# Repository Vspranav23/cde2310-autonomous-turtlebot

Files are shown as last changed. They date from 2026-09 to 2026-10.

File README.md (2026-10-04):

# Autonomous Search, Rescue & Target-Firing Mobile Robot






An end-to-end autonomous mobile robotics system built on TurtleBot, featuring autonomous SLAM frontier exploration, real-time infrared thermal target acquisition, and a custom 3D-printed cam-cantilever-spring ping-pong ball launcher.

<p align="center">
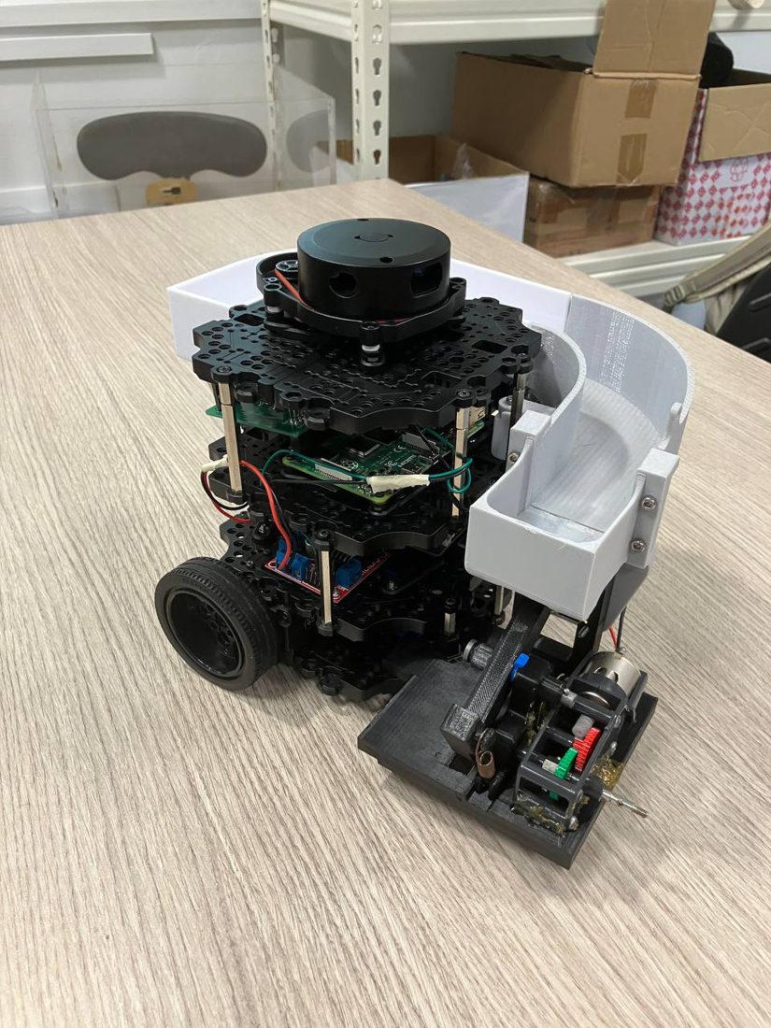
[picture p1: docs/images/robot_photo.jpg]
Assembled TurtleBot with hopper, launcher and thermal sensor
  
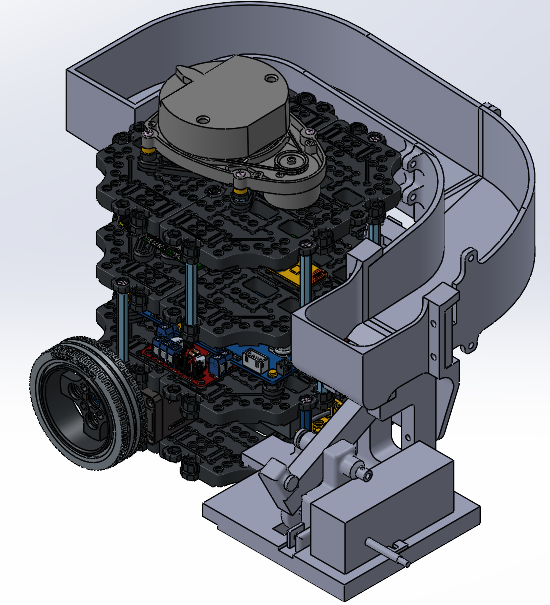
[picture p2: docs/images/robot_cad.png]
CAD model of the robot and payload
  
</p>

---

## System Architecture

```mermaid
graph LR
    subgraph Sensing_and_Perception["Sensing & Perception"]
        LiDAR["2D LiDAR Scanner"] --> SLAM["ROS 2 Cartographer / Nav2"]
        Thermal["AMG8833 8x8 IR Grid"] --> PyThermal["Thermal Vision Node"]
    end

    subgraph Decision_Making["Decision & Navigation"]
        SLAM --> Explorer["Frontier Exploration Node"]
        Explorer --> GoalGen["Nav2 Goal Controller"]
        PyThermal --> LockTarget["Target Lock & Alignment"]
    end

    subgraph Actuation["Actuation & Firing"]
        GoalGen --> Motors["TurtleBot Wheels"]
        LockTarget --> Driver["L298N Motor Driver (GPIO PWM)"]
        Driver --> Launcher["Cam-Cantilever-Spring Launcher"]
    end
```

## Key Features

- **Autonomous Frontier Exploration**: Nav2-integrated frontier exploration node driving complete environment mapping without teleoperation. Uses vectorized NumPy neighbor slicing for millisecond-level frontier discovery.
- **Thermal Heat-Source Tracking**: Real-time 8x8 thermal array processing identifying temperature differentials to detect victims or simulated heat targets.
- **Cam-Cantilever-Spring Launcher**: A geared DC motor rotates a custom surface cam that lifts a lever against an extension spring (14 mm stroke). When the lever drops off the cam step, the spring flicks it up to strike the ping-pong ball. Fed from a gravity hopper (8 balls + 1 in the launcher), and fired in 2 s / 4 s intervals.
- **Distributed ROS 2 Topology**: Workstation host handles heavy SLAM mapping and RViz visualization, while an onboard Raspberry Pi manages motor drivers, thermal I2C bus, and GPIO firing triggers.
- **Dual-Mode Simulation & Hardware Abstraction**: Seamlessly operates in real hardware mode (Raspberry Pi GPIO + Adafruit AMG8833) and standalone simulation mode (Gazebo / software testbed).

## Hardware Bill of Materials (BOM)

| Component | Model / Spec | Interface |
|---|---|---|
| Mobile Base | TurtleBot3 Burger / Custom Chassis | Dynamixel / UART |
| Onboard SBC | Raspberry Pi 4 Model B (4GB) | GPIO / I2C |
| Thermal Sensor | Panasonic / Adafruit AMG8833 | I2C (0x69) |
| Launcher Actuator | RE-260 DC motor + Ta72004 gearbox | L298N motor driver, GPIO PWM |
| 3D Printed Parts | Cam, lever, launcher body (PETG), hopper & sensor mount | Custom SolidWorks files in `/cad` |

## Subsystem Documentation

| Subsystem | README | Covers |
|---|---|---|
| Mechanical | [cad/README.md](cad/README.md) | Cam-cantilever-spring launcher, hopper, sensor mount, assembly, CAD file map |
| Electrical | [Electrical/README.md](Electrical/README.md) | PCB hat, wiring and pin map, power budget, BOM, Gerbers |
| Software | [Software/README.md](Software/README.md) | ROS 2 nodes, topics, thermal codes, launch files, tests |

## Repository Structure

```
├── cad/                     # 3D printable STL and STEP mechanical files
├── docs/                    # Figures (simulated map render)
├── Electrical/              # Schematics and sensor application datasheets
├── Software/
│   ├── cde2310/             # Main ROS 2 package (nodes, launch, params)
│   │   ├── launch/          # full_autonomy_launch.py, rpi.py, laptop.py
│   │   ├── config/          # nav2_params.yaml
│   │   └── cde2310/         # Thermal detection and motion control nodes
│   ├── workspace/           # Colcon workspace sources
│   ├── abandoned/           # Dropped prototypes (solenoid launcher)
│   └── tests/               # Automated maze simulation & unit test trials
└── LICENSE                  # MIT License
```

## Quick Start

### 1. Build the ROS 2 Workspace
```bash
cd Software/workspace
colcon build --symlink-install
source install/setup.bash
```

### 2. Launch Autonomous Search & Fire Routine
On the Raspberry Pi:
```bash
ros2 launch cde2310 rpi.py
```
On the workstation:
```bash
ros2 launch cde2310 laptop.py
```

### 3. Run Automated Maze Simulation Trials
To run the autonomous corridor exploration and thermal target neutralization testbed without physical hardware:
```bash
python Software/tests/test_maze_exploration.py
```
```

---

## Verification & Test Results

The autonomous navigation and target engagement logic was validated against a 12m × 12m maze environment with multi-corridor layouts and hidden heat targets:

```
======================================================================
  AUTOMATED SIMULATION TRIALS: CDE2310 AUTONOMOUS ROBOT
======================================================================
  STATUS: ALL TESTS PASSED (100% SUCCESS)
  - Vectorized Frontier Search: PASSED (0.002s avg)
  - Metric Coordinate Conversion: PASSED
  - Obstacle Blacklist Recovery: PASSED
  - Thermal Alignment & Launcher Firing: PASSED (2/2 targets neutralized)
  - Final Mapping Coverage: 88.0%
======================================================================
```

![Simulated maze (left) and the occupancy grid built during exploration (right)](docs/sim_map.png)

*Left: ground-truth maze with heat targets (stars) and start pose. Right: map uncovered by the simulated LiDAR (grey = unknown) and the poses where scans were taken. The sim moves the robot directly between frontiers without collision checking, so the line is not a drivable path. Regenerate with `python Software/tests/render_sim_map.py`.*

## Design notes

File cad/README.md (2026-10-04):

# Mechanical

The mechanical payload sits on a TurtleBot3 Burger. It has three parts:

- **Hopper:** a gravity-fed, single-stack hopper that holds the ping-pong balls.
- **Launcher:** a cam-cantilever-spring mechanism that flicks one ball at a time upward.
- **Sensor mount:** a holder at the front of the robot for the AMG8833 thermal camera.

All custom parts were modelled in SolidWorks and 3D printed. The launcher parts are PETG.

| Built robot | CAD |
|---|---|
|  |  |

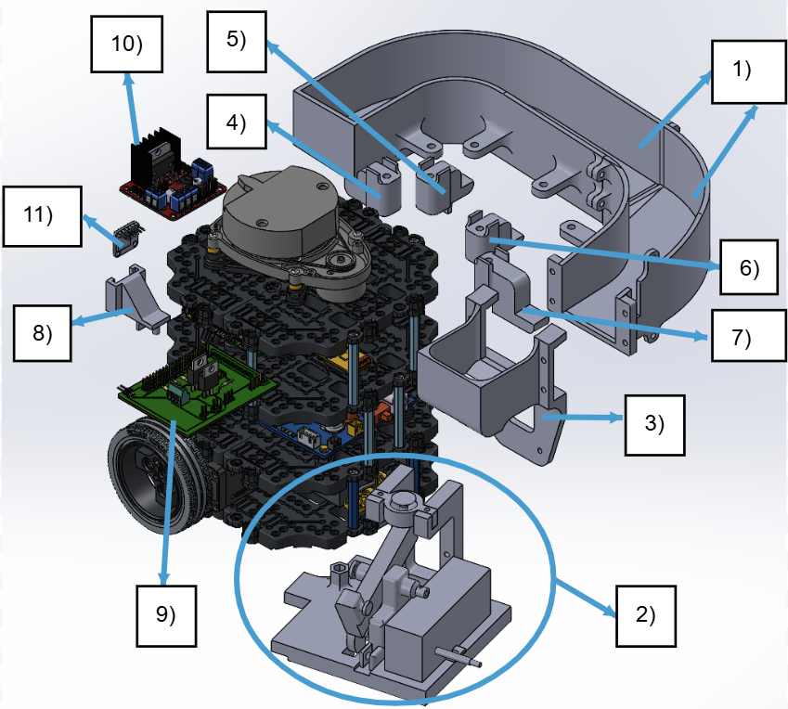
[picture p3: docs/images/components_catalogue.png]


*Components: 1 hopper, 2 launcher, 3 launcher mount, 4–7 spacers 1–4, 8 sensor mount, 9 PCB controller, 10 L298N motor driver, 11 AMG8833 thermal sensor.*

## Specifications

| Item | Value |
|---|---|
| Size (L × W × H) | 300 × 221 × 206 mm |
| Weight | 1575 g unladen, 1600 g with 9 balls |
| Ball capacity | 9 (8 in the hopper, 1 in the launcher) |
| Estimated launch height | 1.0–1.5 m |
| Launcher stroke | 14 mm spring extension, 2 mm pre-load |
| Launcher drive | RE-260 DC motor (3.0–4.5 V) + Ta72004 worm gearbox at 336:1 |

## Launcher: cam-cantilever-spring

A lever pivots on a pin in the launcher mount. One end of the lever rests on a custom surface cam and the other end is attached to an extension spring.

1. The geared motor turns the cam.
2. As the cam turns from its lowest to its highest point, it lifts the lever and stretches the spring.
3. When the lever reaches the cam's step, it drops off.
4. The spring snaps the lever back, and the lever strikes the ball upward.

| CAD | Printed launcher (PETG) |
|---|---|
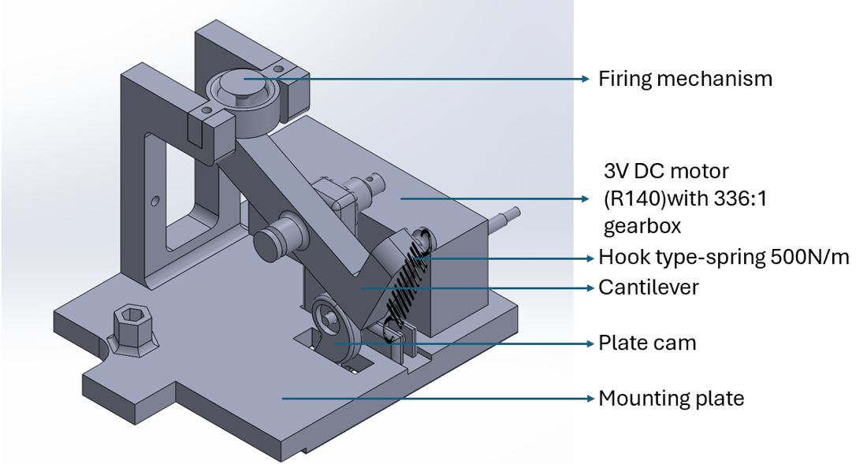
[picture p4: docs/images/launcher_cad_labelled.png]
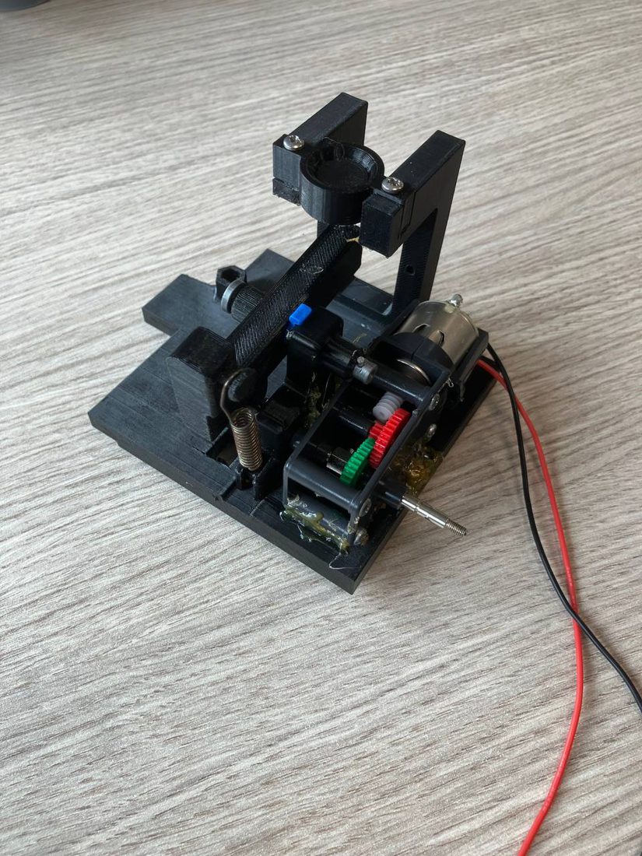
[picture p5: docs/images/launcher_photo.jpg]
|  |  |

| Spring loaded (lever on the cam) | Fired (lever flicked up into the firing pin) |
|---|---|
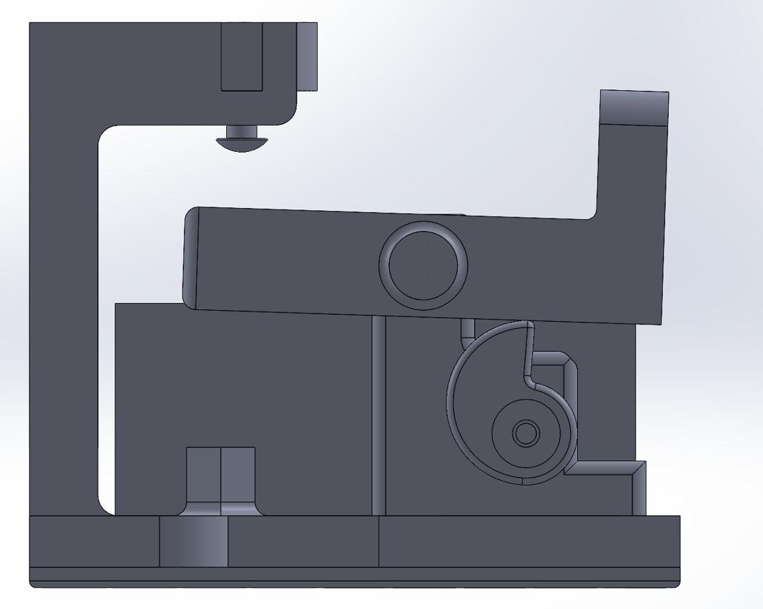
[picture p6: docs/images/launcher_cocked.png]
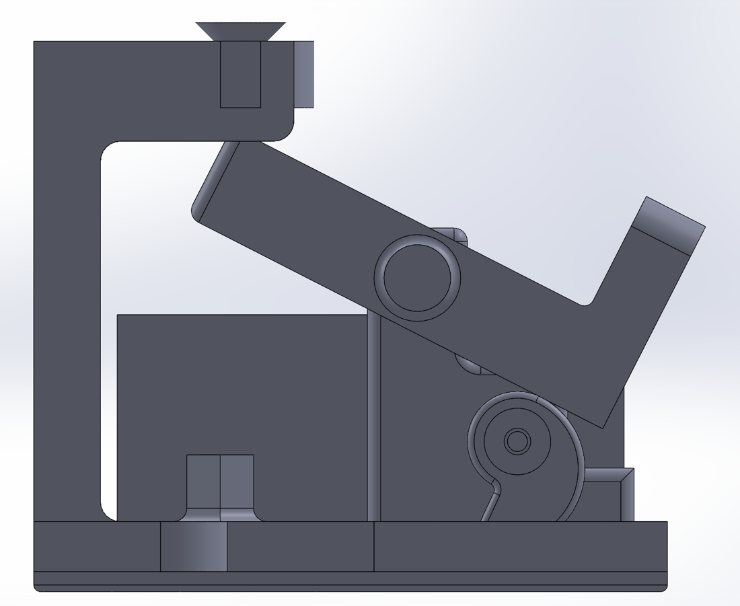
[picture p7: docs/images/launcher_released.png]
|  |  |

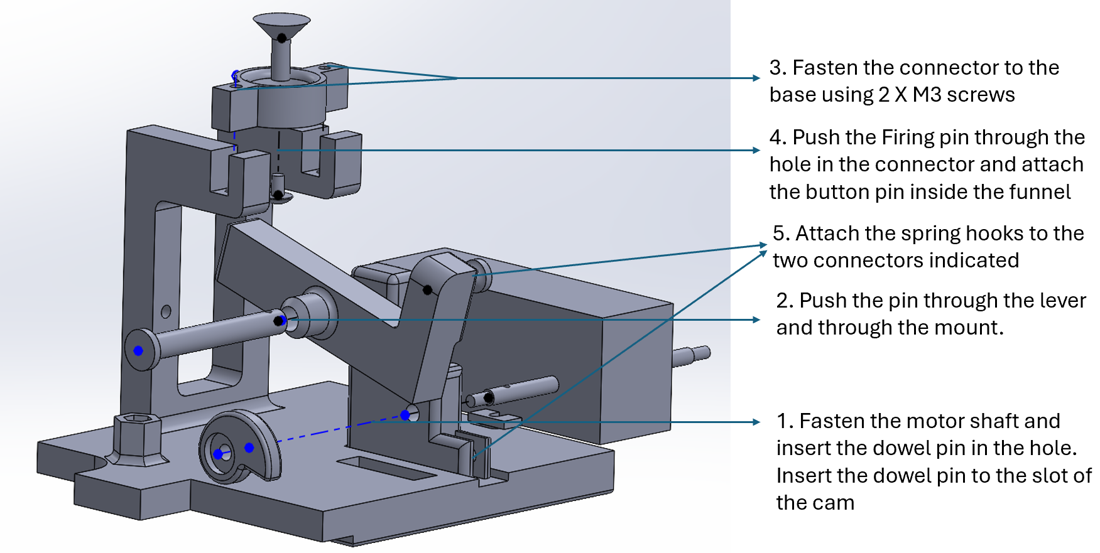
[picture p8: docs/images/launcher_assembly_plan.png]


*Launcher assembly order.*

### Design changes made during testing

| Problem | Change |
|---|---|
| The mounting holes broke under a 20 mm stroke. | Reduced the cam step from 10 mm to 8 mm. Added 10 mm of material around the lever and mount pin holes and moved the holes 5 mm further apart vertically. This gave a 14 mm effective stroke. |
| The cam broke along the notch that holds the motor shaft's dowel pin. | Turned the notch perpendicular to the cam step and filleted every edge. |
| The launcher vibrated while the robot was moving. | Added a waffle-pattern support under the base and attached the base plate to the TurtleBot's plate supports. |
| Friction between the lever and the cam stalled the motor. | Greased all moving parts. |
| The printed pivot pin couldn't carry the spring load. | Drilled a 2 mm bore through the pin and inserted a steel spring dowel. Added a spacer between the lever and the mount. |

| Cracked mounting holes | Broken cam notch | Redesigned cam with fillets |
|---|---|---|
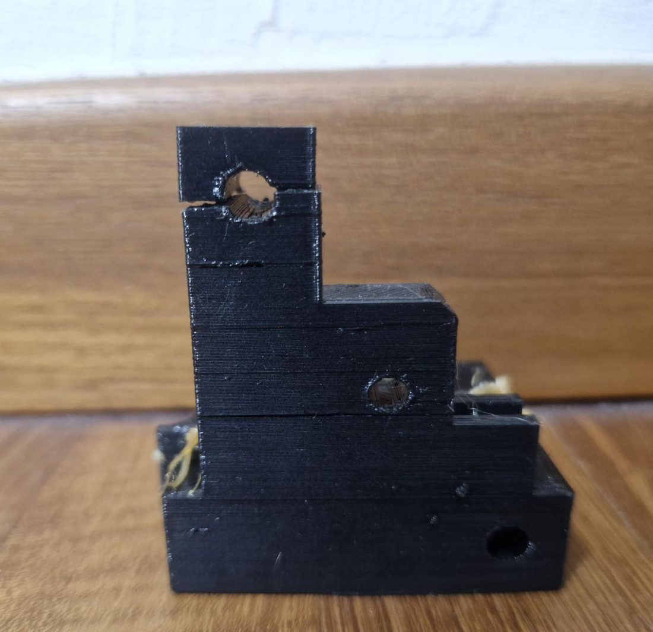
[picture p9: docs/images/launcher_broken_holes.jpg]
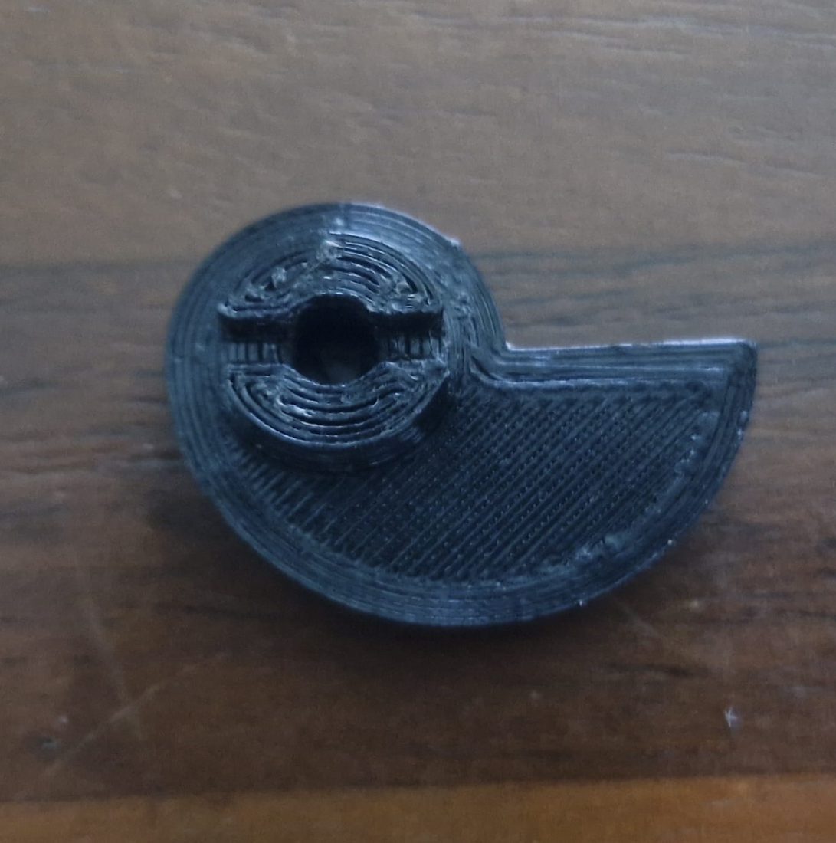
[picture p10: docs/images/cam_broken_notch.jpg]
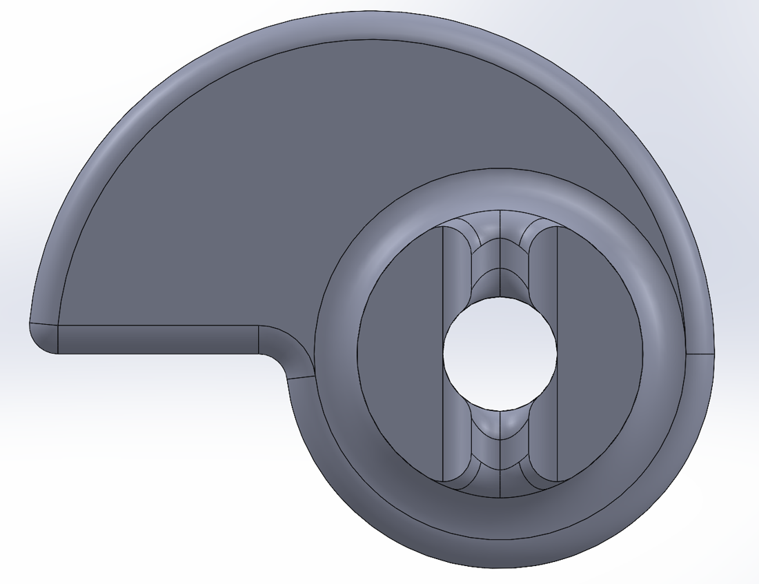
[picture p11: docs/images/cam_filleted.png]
|  |  |  |

| Waffle-pattern base | Pin reinforced with a dowel, plus a spacer |
|---|---|
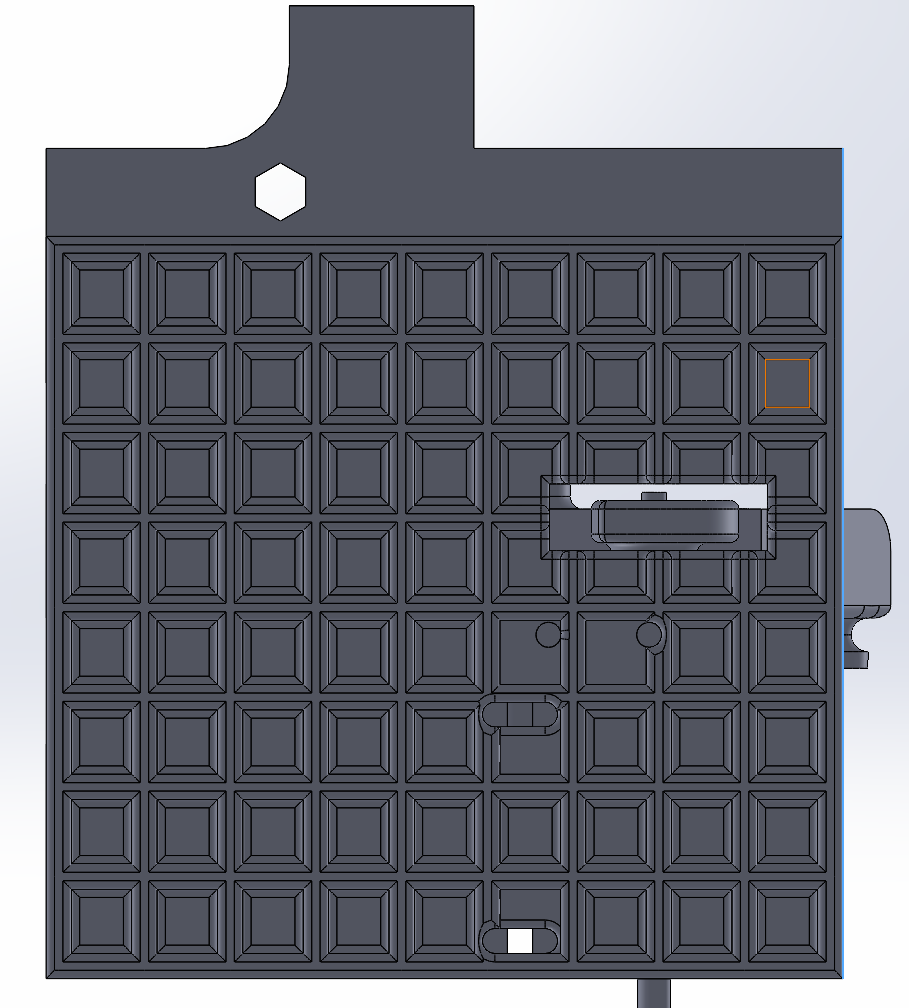
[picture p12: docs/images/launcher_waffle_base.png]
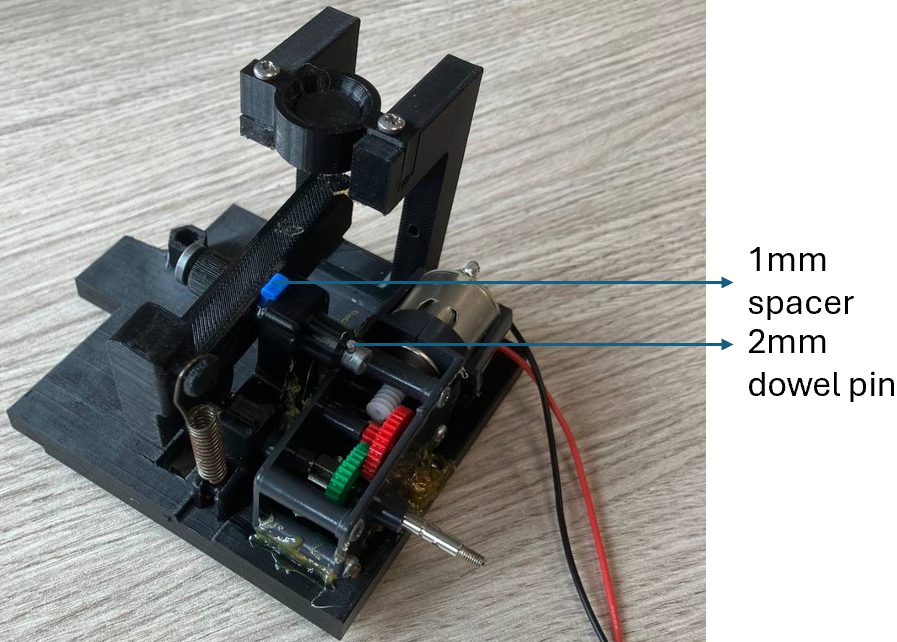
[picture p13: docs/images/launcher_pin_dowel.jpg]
|  |  |

### Known issue

In the final run the cam could not "slip" past the lever, so the lever never flicked. The camshaft was coupled to the gearbox through a brass hex insert with a half-tightened set screw. Too tight and the cam can't slip; too loose and the gearbox can't turn the cam.

Fixes for a next version:

- **Clutch:** add a proper engage/disengage mechanism between the gearbox and the camshaft.
- **Lever angle:** mount the lever at an acute angle to the base instead of nearly horizontal.
- **Spring position:** centre the spring on the lever so the lever doesn't drift sideways.

## Hopper

- **v1** held two layers of balls. Balls jammed near the opening. A separator was added near the opening, but it didn't stop the jams.
- **v2**, the final version, holds a single layer and is printed in two parts. Rough print surfaces made balls stick, so the high end of the hopper is raised on swappable spacers to steepen the slope. It also has a mount that holds the launcher.

| v1: double stack | v1: separator near the opening | v2: single stack on spacers |
|---|---|---|
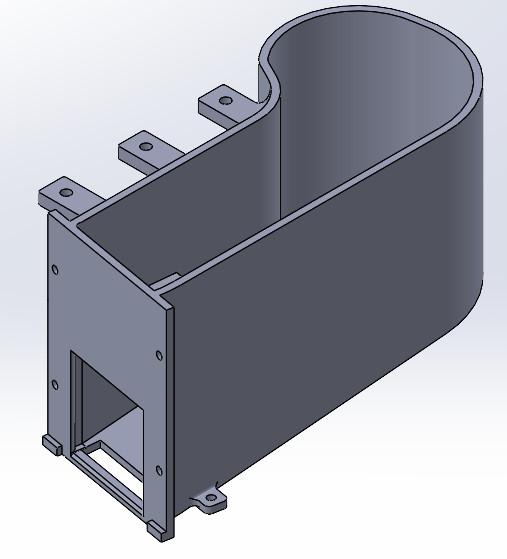
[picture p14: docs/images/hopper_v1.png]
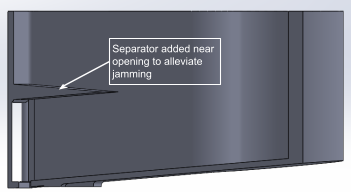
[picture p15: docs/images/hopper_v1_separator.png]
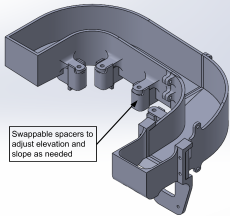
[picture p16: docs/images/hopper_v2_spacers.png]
|  |  |  |

| Final hopper and launcher (CAD) | Final hopper and launcher (printed) |
|---|---|
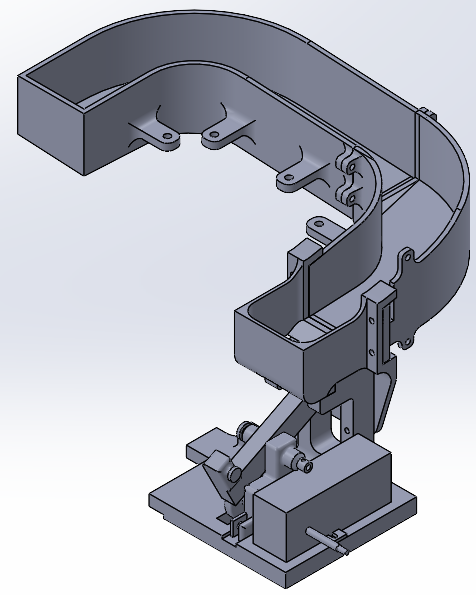
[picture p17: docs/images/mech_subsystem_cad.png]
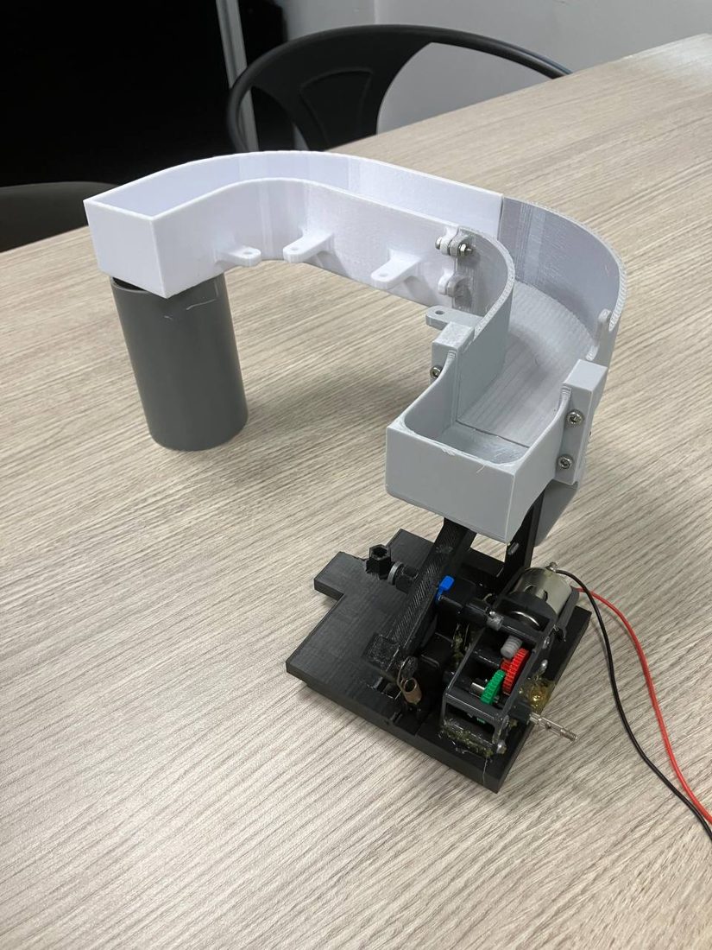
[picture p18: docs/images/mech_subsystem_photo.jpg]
|  |  |

## Sensor mount

The final mount slots into a TurtleBot rivet hole (M4 equivalent). Its slot is deep and narrow enough to hold the AMG8833 firmly. The first version was bolted on, which was hard to reach under the waffle plate, and its slot was too loose for the sensor.

| v1: bolted on | v2: slots into a rivet hole |
|---|---|
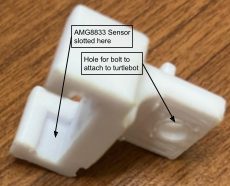
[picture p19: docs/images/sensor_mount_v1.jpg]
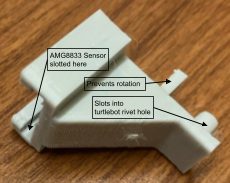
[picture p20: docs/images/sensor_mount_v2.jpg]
|  |  |

## Assembly

Build a stock TurtleBot3 Burger first, using the [ROBOTIS assembly manual](https://emanual.robotis.com/docs/en/platform/turtlebot3/hardware_setup/). Then:

| Step | Instruction | Diagram |
|---|---|---|
| 1 | Install the launcher on the hex supports. You may need to remove the top three waffle plates. |  |
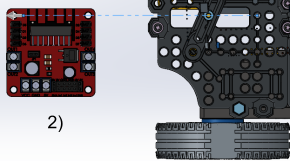
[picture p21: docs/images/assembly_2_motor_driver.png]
| 2 | Install the L298N motor driver on the second waffle plate. Move the OpenCR board if it's in the way. |  |
| 3 | Fasten the two hopper sections and the launcher mount together. |  |
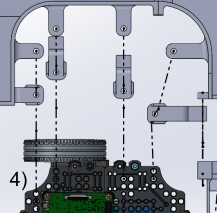
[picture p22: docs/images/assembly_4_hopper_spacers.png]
| 4 | Attach the hopper to the spacers, then fix the spacers to the third waffle plate. Spacers 1–4 are different lengths, so check that each one goes in the right place. |  |
| 5 | Fasten the launcher mount to the launcher. |  |
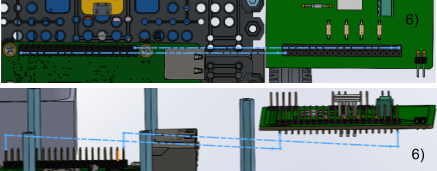
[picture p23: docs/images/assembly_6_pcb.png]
| 6 | Fit the PCB controller onto the Raspberry Pi, matching the GPIO pins to the labels on the PCB. For more room, add M3×10 mm male-female hex extenders to the M3×45 mm supports on the third waffle plate. |  |
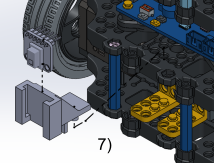
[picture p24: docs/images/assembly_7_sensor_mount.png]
| 7 | Insert the AMG8833 into the sensor mount and fit the mount to the robot. |  |

## Files

| Path | Contents |
|---|---|
| `SolidWorks_source/shooter - lever/lever_v2/` | **Final launcher.** The `shooter_mech.SLDASM` assembly with its cam, lever, pin, spring, mount, body and covers. |
| `SolidWorks_source/shooter - lever/` | Earlier version of the cam launcher. `.stl(2)/` has its print files. |
| `SolidWorks_source/Shooter - Friction Wheel/` | **Final hopper** (`Hopper_v2_part1/2`), `Launcher_mount` and `Spacer1`–`Spacer4`. This folder also holds the friction-wheel launcher concept, which was not built. |
| `SolidWorks_source/Shooter - Friction Wheel/v1 hopper/` | First, double-stack hopper (abandoned). |
| `SolidWorks_source/IR_sensor_holder.SLDPRT` | AMG8833 sensor mount. |
| `SolidWorks_source/Shooter/` | Solenoid launcher prototype (abandoned; see [`Software/abandoned/`](../Software/abandoned/README.md)). |
| `Cannon_2.STL`, `Solenoid_holder.STL`, `Spring_rod_2a.STL`, `plate_2.STL`, `Gate.STL` | Print files for the solenoid prototype (abandoned). |
| `First/Second/Third/Forth Floor.step`, `XM430.step`, `LB-012.step`, `pr30_*`, fasteners | Stock TurtleBot3 Burger parts, used as reference when fitting the payload. |

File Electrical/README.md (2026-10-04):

# Electrical

The electrical payload adds three things to the stock TurtleBot3 Burger:

- an **AMG8833 thermal camera** for finding heat sources
- an **L298N motor driver** that runs the launcher's cam motor
- a **custom PCB hat** on the Raspberry Pi that connects them

Everything runs on the TurtleBot's battery. The PCB takes its power from the OpenCR board's 5 V output.

## System overview

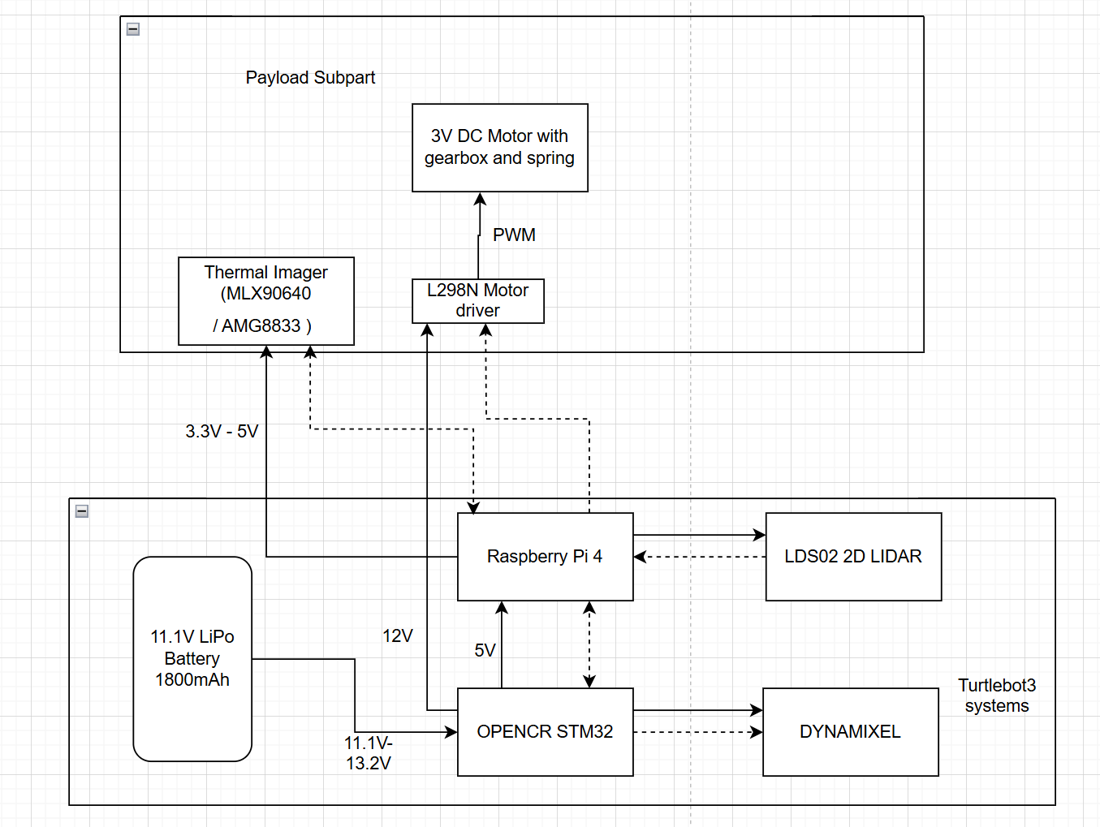
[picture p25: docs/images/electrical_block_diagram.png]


```
3S LiPo (11.1 V, 1800 mAh) ──> OpenCR ──5 V──> PCB hat ──> Raspberry Pi 4 (GPIO header)
                                                  ├──I2C──> AMG8833 thermal camera
                                                  └──GPIO─> L298N motor driver ──> RE-260 motor + gearbox (launcher cam)
```

| Signal | Raspberry Pi pin (BCM) | Used by |
|---|---|---|
| AMG8833 SDA / SCL | GPIO 2 / GPIO 3 (I²C-1, address 0x69) | `thermal` node |
| L298N IN1 (PWM, 1 kHz) | GPIO 18 | `startFiring()` in the explorer node, `Software/test_firing.py` |
| L298N IN2 (held low) | GPIO 27 | same |
| Set HIGH at startup | GPIO 17 | explorer node (presumably the L298N enable pin) |

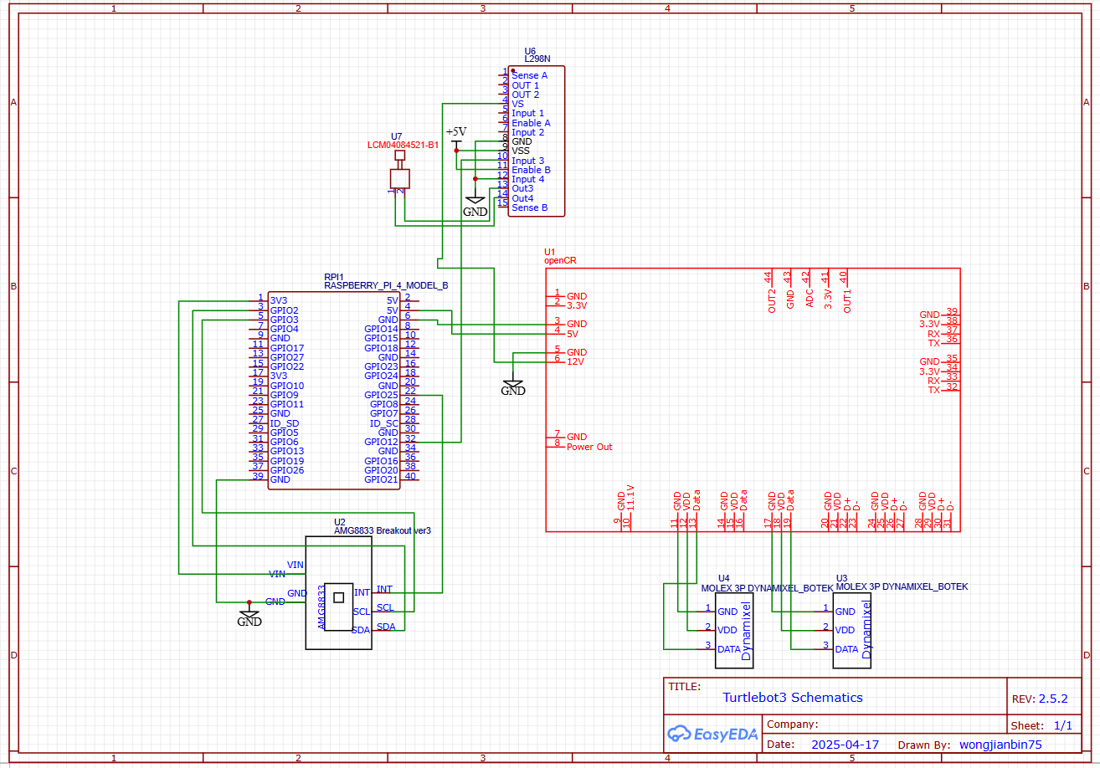
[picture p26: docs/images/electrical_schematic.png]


*Wiring schematic for the whole system.*

The L298N was added late in the project (week 12), after the solenoid design was dropped. It isn't on the PCB, so it's wired to the Pi header with jumper wires.

## Specifications

| Item | Value |
|---|---|
| Battery | 3S1P LiPo, 11.1 V nominal, 1800 mAh (19.98 Wh) |
| TurtleBot power draw | 6.7 W idle; 10.7 W at max speed (11.3 W peak) |
| Launcher motor + L298N | about 5 W (5.5 W peak) |
| Estimated run time | 0.6–1.0 h (mission length is 25 min) |
| AMG8833 | 8×8 IR array, 60° field of view, 0–80 °C range, ±2.5 °C accuracy, 3–5 V supply |
| L298N | 5–35 V motor supply, 20 W max |
| PCB hat | 5 V input, max 4 A (limited by the OpenCR's 5 V output), 71 × 56 × 31 mm, 30 g |

Power was measured with the robot running from a bench supply set to 12.3 V, 1.0 A max. Power peaks while the robot boots, then settles to about 6.7 W at idle:

| Run 1 | Run 2 | Run 3 |
|---|---|---|
|  |  |  |

## The onboard Raspberry Pi PCB

The PCB hat was designed with a lot of help from Mr. Eugene to make the wiring tidier and more reliable.

- **Connections:** it passes through the Pi's GPIO and I²C pins. Pin 24 (GPIO 8) is the exception (see Known issues).
- **Headers:** the board has headers for the `AMG8833`, a `SERVO`, and the `5VSOLENOID` and `12VSOLENOID` outputs. It also has a 5 V / 12 V screw terminal block.
- **MOSFET outputs:** two IRL3803 MOSFETs (Q1, Q2) switch the two solenoid outputs. These were for the solenoid launcher, which was abandoned. The final launcher doesn't use them.
- **Manufacture:** five boards were ordered from JLCPCB, which ran a flying-probe electrical test on them. One was assembled in-house at the E2 Electronics Lab.
- **Testing:** the assembled board was checked with a 5 V supply and a 3.3 V signal to confirm a Pi GPIO pin can switch the MOSFETs. It was then integrated with a backup Raspberry Pi to confirm AMG8833 data can be read through it.



### Known issues

1. **Pin 24 (GPIO 8) is not soldered.** A via sits too close to it and could short.
2. **Hard-to-reach pins:** the design didn't allow for the gap between the TurtleBot waffle plates. M3×10 mm hex extenders on the M3×45 mm supports give more room.
3. **Header doesn't fully seat:** the Pi's Ethernet port is in the way, so the header can't press all the way down. The back of the board is taped over so the port's metal casing can't short the pins.
4. **No mechanical fastening:** the board can work loose when the robot vibrates.
5. **Exposed wiring:** the L298N is not on the PCB, so its jumper wires are left exposed.

For a next version: plan for the space between the waffle plates and the Ethernet port, screw the board down, and put the motor driver on the PCB.

### Schematics


### Bill of materials

<table>
<tr><td><b>Qty</b></td><td><b>Value</b></td><td><b>Device</b></td><td><b>Footprint Name</b></td><td><b>Parts</b></td><td><b>Detailed Description</b></td><td><b>CATEGORY</b></td><td><b>CREATED_BY</b></td><td><b>DATASHEET</b></td><td><b>DESCRIPTION</b></td><td><b>DIGIKEY_PART_NUMBER</b></td><td><b>DIGI_KEY_PART_NUMBER</b></td><td><b>DRAIN_CURRENT</b></td><td><b>IC_MAX</b></td><td><b>MANUFACTURER</b></td><td><b>MPN</b></td><td><b>OPERATING_TEMPERATURE</b></td><td><b>PACKAGE_SIZE</b></td><td><b>PACKAGE_TYPE</b></td><td><b>PART_STATUS</b></td><td><b>PITCH</b></td><td><b>POPULARITY</b></td><td><b>ROHS</b></td><td><b>SERIES</b></td><td><b>SUBCATEGORY</b></td><td><b>TEMPERATURE_COEFFICIENT</b></td><td><b>THERMALLOSS</b></td><td><b>TOLERANCE</b></td><td><b>TYPE</b></td><td><b>VCEO_MAX</b></td></tr>
<tr><td>2</td><td>10k</td><td>R_AXIAL-7.2MM-PITCH</td><td>RESAD724W46L381D178B</td><td>R6, R8</td><td>Resistor Fixed - Generic</td><td>Resistors</td><td></td><td></td><td>Axial Resistor 7.24 mm pitch 3.81 mm body length 1.78 mm body diameter</td><td></td><td></td><td></td><td></td><td></td><td></td><td></td><td>AXIAL</td><td>THT</td><td></td><td></td><td></td><td></td><td></td><td></td><td></td><td></td><td></td><td></td><td></td></tr>
<tr><td>2</td><td>1N4148DO35-10</td><td>1N4148DO35-10</td><td>DO35-10</td><td>D3, D4</td><td>DIODE</td><td></td><td></td><td></td><td></td><td></td><td></td><td></td><td></td><td></td><td></td><td></td><td></td><td></td><td></td><td></td><td>21</td><td></td><td></td><td></td><td></td><td></td><td></td><td></td><td></td></tr>
<tr><td>2</td><td>1k</td><td>R_AXIAL-7.2MM-PITCH</td><td>RESAD724W46L381D178B</td><td>R5, R7</td><td>Resistor Fixed - Generic</td><td>Resistors</td><td></td><td></td><td>Axial Resistor 7.24 mm pitch 3.81 mm body length 1.78 mm body diameter</td><td></td><td></td><td></td><td></td><td></td><td></td><td></td><td>AXIAL</td><td>THT</td><td></td><td></td><td></td><td></td><td></td><td></td><td></td><td></td><td></td><td></td><td></td></tr>
<tr><td>1</td><td>2828XX-4282834-4</td><td>2828XX-4282834-4</td><td>TERMBLK_254-4N</td><td>5V,12VTERBLK</td><td>4 Position Wire to Board Terminal Block Horizontal with Board</td><td>Fixed Terminal Blocks</td><td></td><td>https://www.te.com/usa-en/product-282834-4.datasheet.pdf</td><td>4 Position Wire to Board Terminal Block Horizontal with Board 0.100" (2.54mm) Through Hole</td><td></td><td></td><td></td><td></td><td>TE Connectivity AMP Connectors</td><td>282834-4</td><td>-40�C ~ 105�C</td><td>NA</td><td>THT</td><td>ACTIVE</td><td>0.100" (2.54mm) </td><td></td><td>COMPLIANT</td><td>Buchanan</td><td>Terminal Blocks</td><td></td><td></td><td></td><td>Through Hole Screw - Rising Cage Clamp Side wire entry Horizontal with Board</td><td></td></tr>
<tr><td>2</td><td>61300211121</td><td>61300211121</td><td>61300211121</td><td>5VSOLENOID, 12VSOLENOID</td><td>CONN HEADER VERT 2POS 2.54MM</td><td></td><td>PCBLayout.com</td><td></td><td></td><td></td><td>732-5315-ND</td><td></td><td></td><td>Wurth Electronics Inc.</td><td>61300211121</td><td></td><td></td><td></td><td></td><td></td><td></td><td></td><td></td><td></td><td></td><td></td><td></td><td></td><td></td></tr>
<tr><td>1</td><td>61300311121</td><td>61300311121</td><td>61300311121</td><td>SERVO</td><td>CONN HEADER VERT 3POS 2.54MM</td><td></td><td>PCBLayout.com</td><td></td><td></td><td></td><td>732-5316-ND</td><td></td><td></td><td>Wurth Electronics Inc.</td><td>61300311121</td><td></td><td></td><td></td><td></td><td></td><td></td><td></td><td></td><td></td><td></td><td></td><td></td><td></td><td></td></tr>
<tr><td>1</td><td>61300511121</td><td>61300511121</td><td>61300511121</td><td>AMG8833</td><td>CONN HEADER VERT 5POS 2.54MM</td><td></td><td>PCBLayout.com</td><td></td><td></td><td></td><td>732-5318-ND</td><td></td><td></td><td>Wurth Electronics Inc.</td><td>61300511121</td><td></td><td></td><td></td><td></td><td></td><td></td><td></td><td></td><td></td><td></td><td></td><td></td><td></td><td></td></tr>
<tr><td>2</td><td>61302011121</td><td>61302011121</td><td>61302011121</td><td>GPIO_EVEN, GPIO_ODD</td><td>CONN HEADER VERT 20POS 2.54MM</td><td></td><td>PCBLayout.com</td><td></td><td></td><td>732-5329-ND</td><td></td><td></td><td></td><td>Wurth Electronics Inc.</td><td>61302011121</td><td></td><td></td><td></td><td></td><td></td><td></td><td></td><td></td><td></td><td></td><td></td><td></td><td></td><td></td></tr>
<tr><td>2</td><td>NMOSFET_TO220</td><td>NMOSFET_TO220</td><td>TO220BV</td><td>Q1, Q2</td><td>N-Channel MOSFET - Generic</td><td>Transistor</td><td></td><td>https://www.diodes.com/assets/Package-Files/TO220-3.pdf</td><td>Generic N Channel MOSFET TO220 Package Through Hole</td><td></td><td></td><td></td><td></td><td></td><td></td><td></td><td>TO220</td><td>THT</td><td></td><td></td><td></td><td></td><td></td><td>MOSFET</td><td></td><td></td><td></td><td>N-Channel</td><td></td></tr>
<tr><td>1</td><td>PINHD-1X2/90</td><td>PINHD-1X2/90</td><td>1X02/90</td><td>JP1</td><td>PIN HEADER</td><td>Headers</td><td></td><td></td><td>Header-Right Angle-2 Position</td><td></td><td></td><td></td><td></td><td></td><td></td><td></td><td></td><td>THT</td><td></td><td>0.100" (2.54mm)</td><td></td><td></td><td></td><td>Headers-Male Pins</td><td></td><td></td><td></td><td>Board to Board or Cable-Unshrouded-Through Hole-Right Angle</td><td></td></tr>
</table>

You may also need a female 2×20 header with 2.54 mm pitch to connect the PCB to the Raspberry Pi.

### 3D model




> [!NOTE]
> The Gerber files are in [`PCB schematic v36_2025-03-21.zip`](PCB%20schematic%20v36_2025-03-21.zip).

## Datasheets

- [Panasonic AMG8833 datasheet](panasonic%20AMG8833%20datasheet.pdf)
- [Adafruit AMG8833 application note](Adafruit%20AMG8833%20Application%20note.pdf)
- [L298N motor driver datasheet](https://components101.com/sites/default/files/component_datasheet/L298N-Motor-Driver-Datasheet.pdf)

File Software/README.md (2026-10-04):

# Software

The software runs on ROS 2 Humble and is split across two machines:

- **Raspberry Pi (on the robot):** TurtleBot bringup, the thermal detection node and the frontier explorer, which also triggers the launcher.
- **Laptop:** SLAM Toolbox, the Nav2 stack and RViz.

## How it fits together

```
 AMG8833 ──I2C──> [thermal] ──/thermal_data──┐
                                             v
 LiDAR ──> slam_toolbox ──/map──────────> [explorer] ──NavigateToPose──> Nav2 ──> wheels
 OpenCR ─────────────────────/odom───────────┘    └──GPIO PWM──> L298N ──> launcher cam motor
```



*Planned mission flow.*

The explorer node runs its decision loop every 2 s:

1. **Heat seen:** if the latest `/thermal_data` message isn't `N`, it follows the heat source:

   | Code | Meaning | Explorer action |
   |---|---|---|
   | `N` | No heat in view (under 5% of pixels above threshold) | Keep exploring frontiers |
   | `L` / `R` | Heat is to the left or right | Rotate 45° toward it |
   | `F<n>` | Heat is ahead, with `n` hot pixels in the centre columns | Drive forward 0.5 m (n ≤ 8), 0.25 m (n ≤ 32) or 0.1 m (n > 32) |
   | `S` | At least 50% of pixels are hot, so the target is in range | Fire the launcher, remember this position, resume exploring |

2. **No heat, not moving:** it picks the nearest unvisited frontier at least 0.3 m away and sends it to Nav2 as a `NavigateToPose` goal. A frontier is a free cell next to unknown space. If Nav2 rejects the goal, that frontier is blacklisted and the explorer picks another.

## Packages

| Package | Path | Executable | What it does |
|---|---|---|---|
| `cde2310` | `workspace/src/cde2310/` | `thermal` | Reads the AMG8833 8×8 grid once a second and publishes the codes above on `/thermal_data`. The `threshold` parameter defaults to 30.0 °C. Set `use_sim:=true`, or run without the sensor, and it republishes whatever arrives on `/sim_thermal_command`. |
| `custom_explorer` | `workspace/src/Autonomous-Explorer-and-Mapper-ros2-nav2/` | `explorer` | Frontier exploration, heat following and firing. Based on [AniArka/Autonomous-Explorer-and-Mapper-ros2-nav2](https://github.com/AniArka/Autonomous-Explorer-and-Mapper-ros2-nav2). Subscribes to `/map`, `/odom` and `/thermal_data`. Set `is_sim:=true` to skip GPIO. |

The Nav2 tuning (costmaps, inflation radius, planner) lives in `workspace/src/cde2310/config/nav2_params.yaml`. That's the file the launch files load. `Software/nav2_params.yaml` is an older copy and is different.

### Launch files (`cde2310/launch/`)

| File | Run on | Starts |
|---|---|---|
| `rpi.py` | Raspberry Pi | TurtleBot3 bringup, then after 10 s the `explorer` and `thermal` nodes |
| `laptop.py` | Laptop | SLAM Toolbox, Nav2 (with the params above) and RViz |
| `full_autonomy_launch.py` | One machine, simulation | SLAM Toolbox, Nav2, `explorer` and `thermal`, all with `use_sim_time:=true` |

## Build and run

```bash
cd Software/workspace
colcon build --symlink-install
source install/setup.bash

# On the Raspberry Pi
ros2 launch cde2310 rpi.py

# On the laptop (same ROS_DOMAIN_ID)
ros2 launch cde2310 laptop.py
```

Dependencies:

- ROS 2 Humble, `turtlebot3_bringup`, `slam_toolbox`, `nav2_bringup`
- `numpy`, `tf_transformations`
- On the Pi only: `RPi.GPIO` and `adafruit-circuitpython-amg88xx`, with I²C enabled

## Standalone scripts

These scripts were used to check one piece of hardware at a time on the Pi. None of them is part of the ROS packages.

| File | Purpose |
|---|---|
| `test_firing.py` | Fires the launcher three times with the competition timing (2 s, then 4 s). It runs the cam motor at 1 kHz PWM, 20% duty, for 5 s per shot, on GPIO 18 (IN1) with GPIO 27 (IN2) held low. |
| `thermal.py` | Prints the raw 8×8 AMG8833 temperature grid every second, to check the sensor works. |
| `tfake_thermal.py` | ROS node that publishes a fixed `N` on `thermal_data`. Use it to test exploration without the sensor. |
| `servo.py` | Sweeps an SG90 servo on GPIO 13. Left over from the servo-gated launcher designs. |
| `launch.py` | Opens Gazebo (TurtleBot3 world) and RViz in separate terminals. |
| `oldNav.py` | First version of the explorer node, before heat following was added. |
| `abandoned/plunger.py` | Solenoid launcher test (abandoned; see `abandoned/README.md`). |

## Simulation test

`tests/test_maze_exploration.py` runs the real `ExplorerNode` frontier logic without ROS. It uses a simulated 12 m × 12 m maze with a ray-cast LiDAR and two heat targets.

```bash
python Software/tests/test_maze_exploration.py   # numpy only
python Software/tests/render_sim_map.py          # + matplotlib, writes docs/sim_map.png
```

The robot jumps straight to each chosen frontier and nothing checks for collisions. So the test checks frontier selection and the thermal-to-fire logic, not navigation.

## Testing results on the robot

| Part | Result |
|---|---|
| Thermal node | Worked. Direction codes were accurate and published reliably. |
| Nav2 with goals set in RViz | Worked. |
| Frontier exploration | Worked. Frontiers were found from the SLAM map and reached. |
| SLAM Toolbox | Worked. Maps were accurate and loop closure kept drift low. |
| Launcher triggered by a fake `S` | Worked through GPIO. |
| **Full integration (thermal + exploration)** | **Failed in the final run.** The thermal node published `N` every second, and each `N` made the explorer call `explore()` again even while it was already navigating. The robot kept picking new frontiers and dropping them, so it only inched forward or jittered. |

The current `check_heat_source()` only calls `explore()` when `is_navigating` is false, which should stop that loop. This fix hasn't been tested on the robot.

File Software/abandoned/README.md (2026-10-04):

# Abandoned designs

Code for mechanisms that were prototyped and then dropped. Kept for reference only; nothing here is used by the robot.

| File | Design | Why it was dropped |
|---|---|---|
| `plunger.py` | Pull-type solenoid launcher (GPIO 20 switches the solenoid via MOSFET) | The solenoid only reaches its rated force when fully retracted, so it could hold the launch spring but not stretch it. Replaced by the cam-cantilever-spring launcher, driven by `../test_firing.py` and `startFiring()` in the explorer node. |

## Solenoid launcher

| Prototype parts | Solenoid force vs. stroke and current |
|---|---|
|  |  |

The force curve (orange) shows the problem: the solenoid's force drops sharply as the gap opens, falling to about 2 mN at 20 mm. A solenoid can hold a spring that's already compressed, but it can't stretch one.

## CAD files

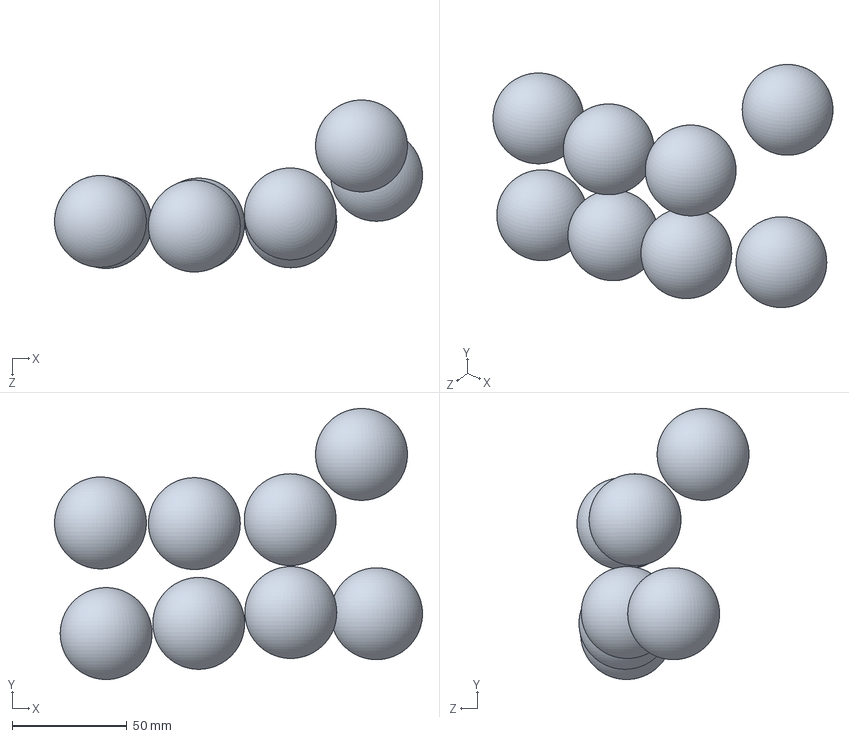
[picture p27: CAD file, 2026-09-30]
cad/SolidWorks_source/Hopper_test.SLDASM
160.2 x 118.0 x 74.9 mm
PingPongBall x 8

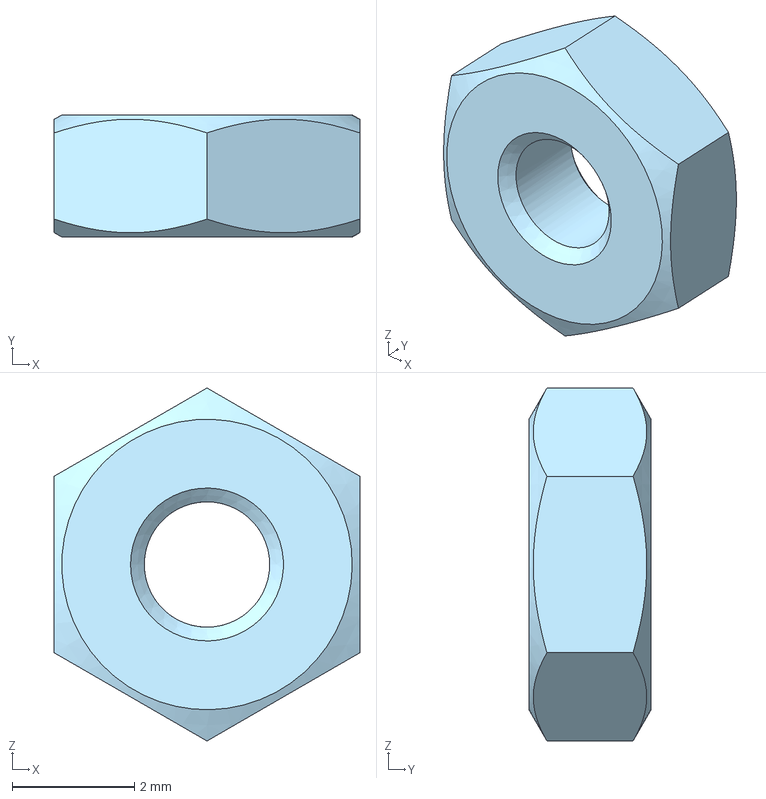
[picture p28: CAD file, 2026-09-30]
cad/NUT2_M2_5.step
5.00 x 2.00 x 5.77 mm

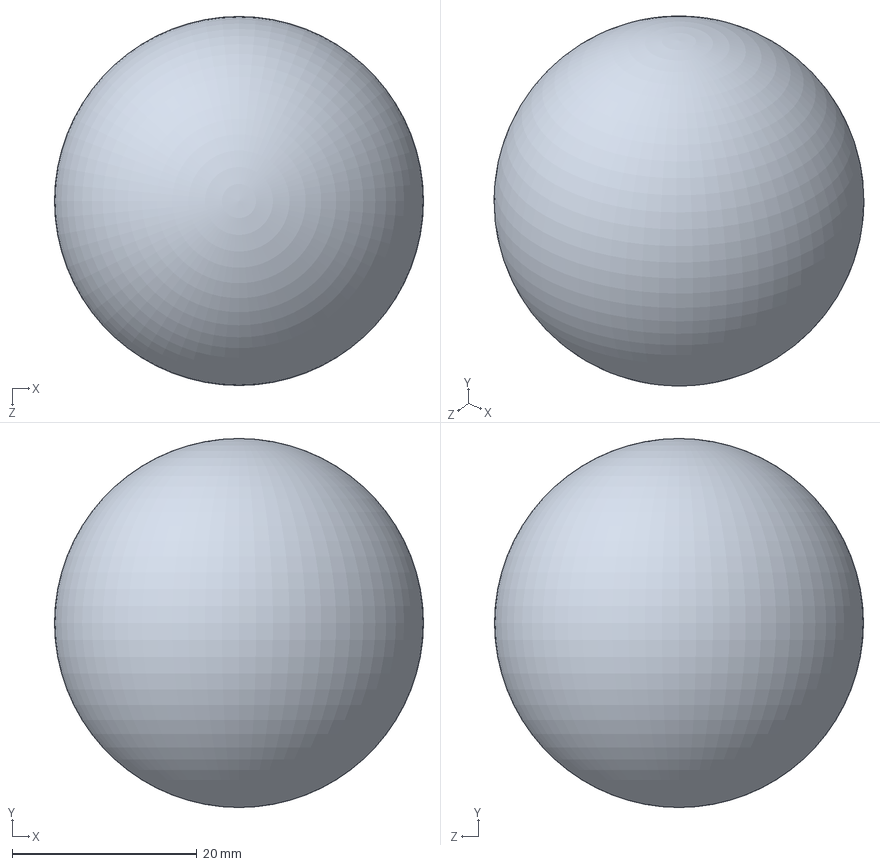
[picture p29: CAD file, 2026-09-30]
cad/SolidWorks_source/PingPongBall.SLDPRT
40.0 x 40.0 x 40.0 mm

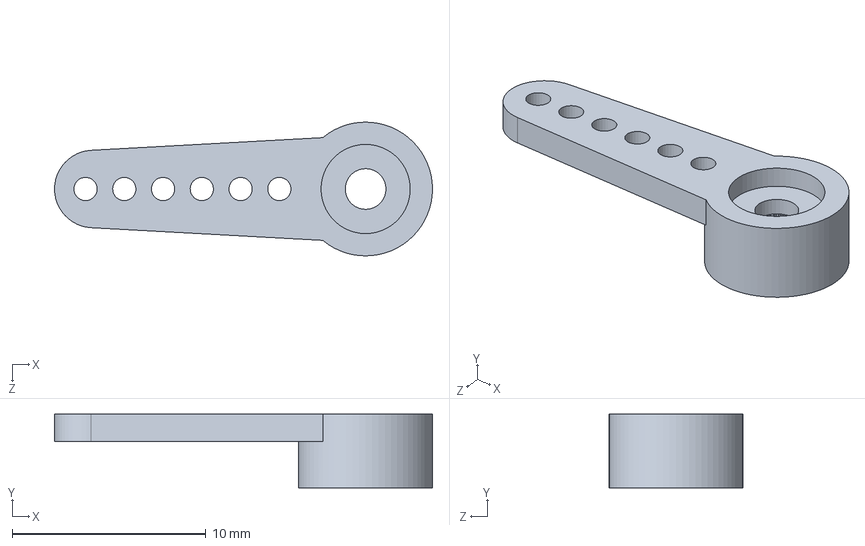
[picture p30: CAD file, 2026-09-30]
cad/SolidWorks_source/Shooter - Friction Wheel/Micro Servo/SG90 - Micro Servo 9g - Tower Pro.2.SLDPRT
19.5 x 3.80 x 6.90 mm

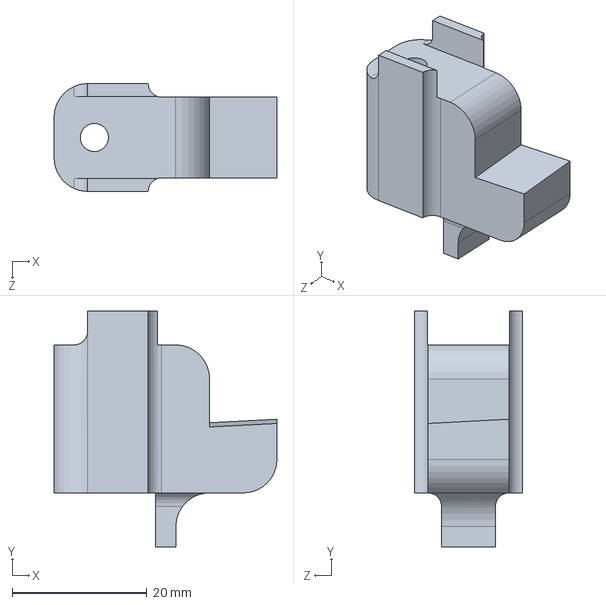
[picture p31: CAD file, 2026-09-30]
cad/SolidWorks_source/Shooter - Friction Wheel/Spacer1.SLDPRT
33.1 x 35.0 x 16.0 mm

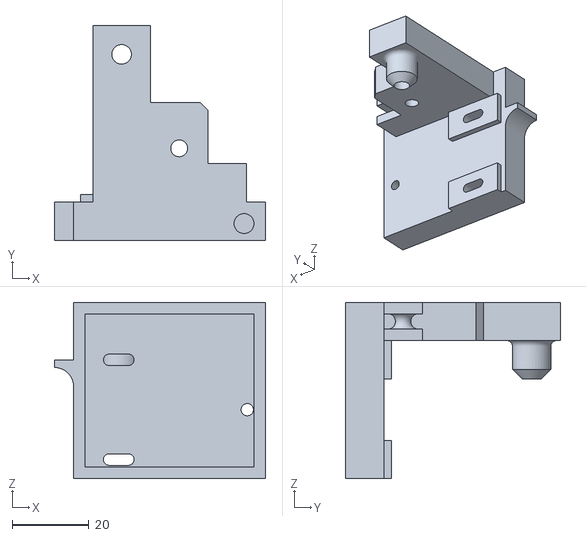
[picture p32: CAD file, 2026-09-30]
cad/SolidWorks_source/shooter - lever/.stl(2)/mount.STL
55.0 x 56.0 x 46.0

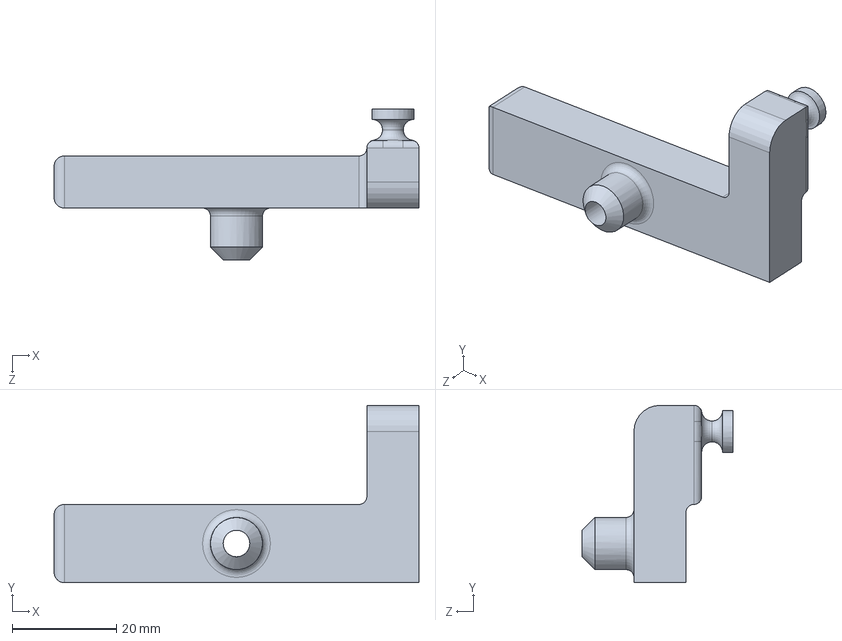
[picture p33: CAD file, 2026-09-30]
cad/SolidWorks_source/shooter - lever/lever.SLDPRT
70.0 x 34.0 x 29.0 mm

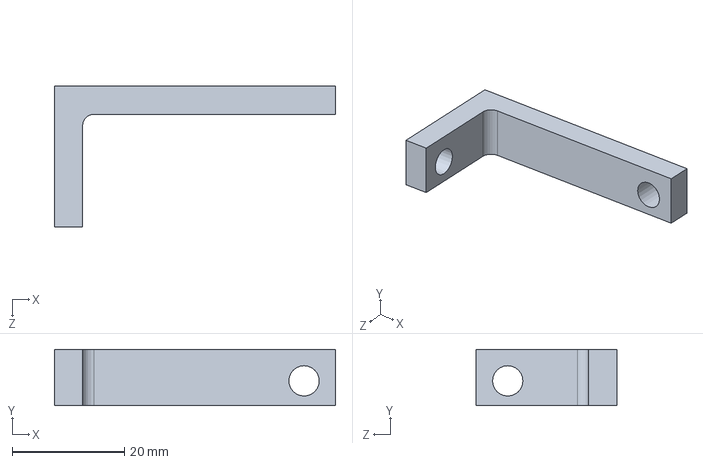
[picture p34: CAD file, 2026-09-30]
cad/SolidWorks_source/shooter - lever/lever_v2/l_plate.SLDPRT
50.0 x 10.0 x 25.0 mm

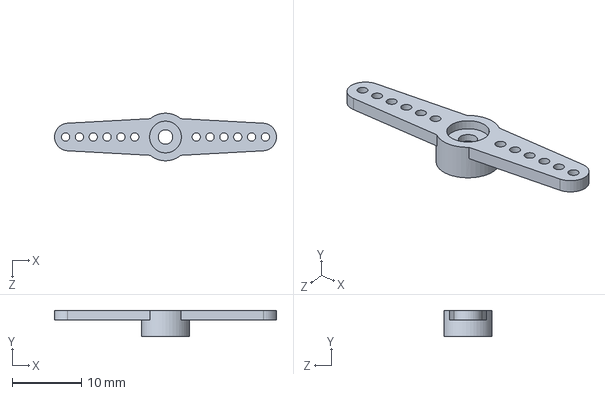
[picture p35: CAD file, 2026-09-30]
cad/SolidWorks_source/Shooter/Micro Servo/SG90 - Micro Servo 9g - Tower Pro.3.SLDPRT
32.1 x 3.80 x 6.90 mm

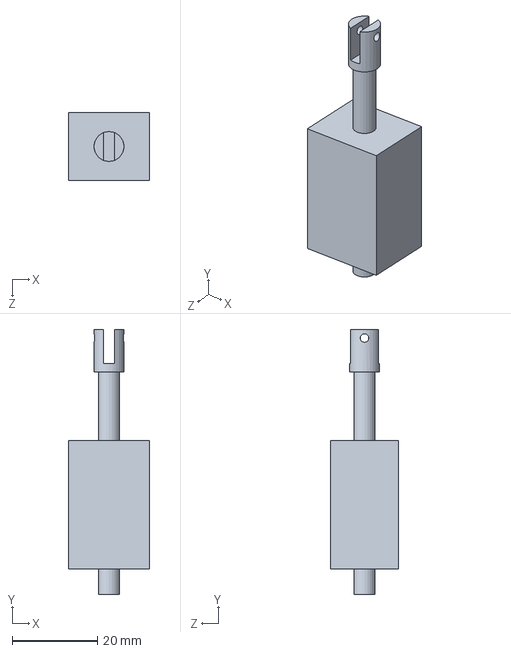
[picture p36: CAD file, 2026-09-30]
cad/SolidWorks_source/Shooter/Solenoid_2.SLDPRT
19.0 x 62.0 x 16.0 mm

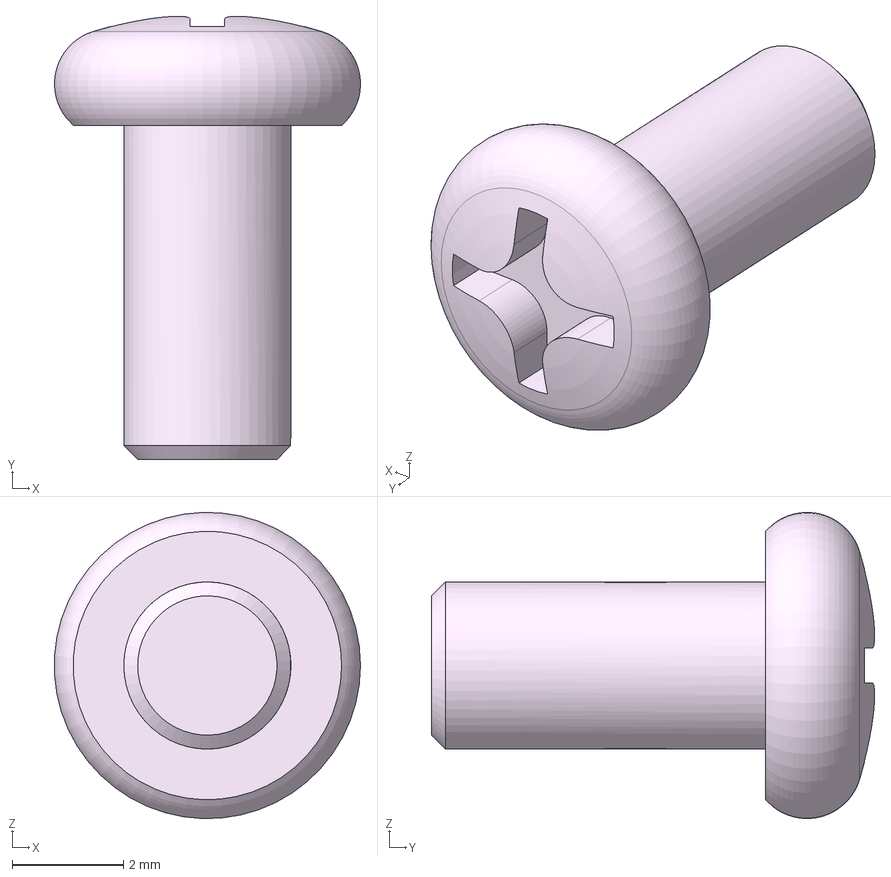
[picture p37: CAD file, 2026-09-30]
cad/PHS_M3X6.step
5.49 x 7.96 x 5.50 mm

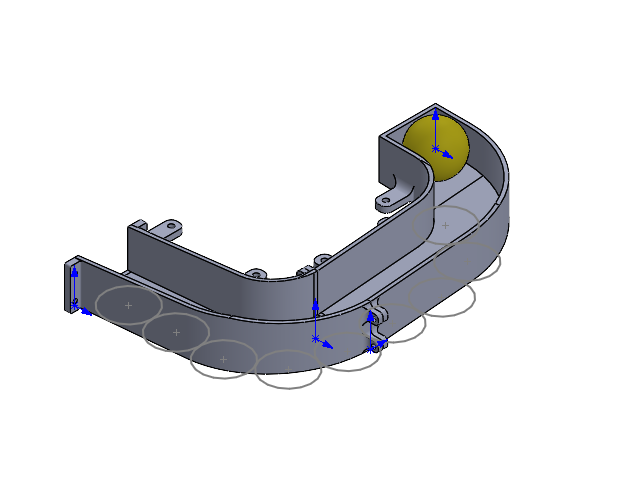
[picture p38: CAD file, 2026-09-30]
cad/SolidWorks_source/Shooter - Friction Wheel/v1 hopper/v1_Hopper_Assem.SLDASM
Hopper_part1
Hopper_part2

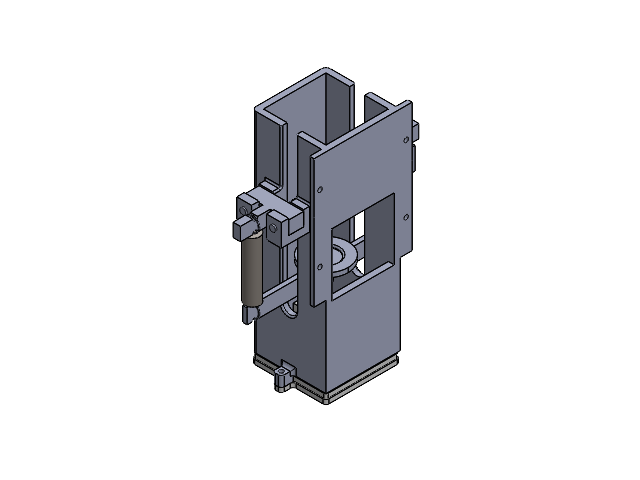
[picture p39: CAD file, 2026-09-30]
cad/SolidWorks_source/Shooter/Cannon_Assem_part.SLDASM
Cannon_2
Solenoid_2
plate_2
Spring_rod_2a x 2
Pin_2 x 4
Spring_2 x 2
Solenoid_holder

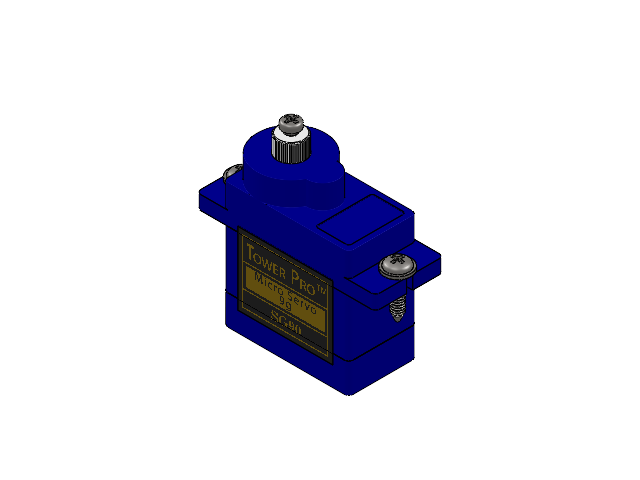
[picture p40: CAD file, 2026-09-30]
cad/SolidWorks_source/Shooter - Friction Wheel/Micro Servo/SG90 - Micro Servo 9g - Tower Pro.SLDASM
SG90 - Micro Servo 9g - Tower Pro.1
SG90 - Micro Servo 9g - Tower Pro.5 x 2
SG90 - Micro Servo 9g - Tower Pro.6

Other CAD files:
cad/SolidWorks_source/shooter - lever/lever_v2/shooter_mech.SLDASM
cad/SolidWorks_source/shooter - lever/shooter_mech.SLDASM
cad/SolidWorks_source/Shooter - Friction Wheel/Hopper_launcher_Assem.SLDASM
cad/Cannon_2.STL
cad/First Floor.step
cad/Forth Floor.step
cad/Gate.STL
cad/LB-012.step
cad/M_PR07_A01_SPACER_RIVET.step
cad/NUT2_M3.step
cad/PHS_M2X4.step
cad/PHS_M2_5X12.step
cad/PHS_M2_5X16.step
cad/PR07_ONE_RIVET_2.step
cad/PR21_CASTER_CVR_3X5_REV6.step
cad/STEELBALL_3_8INCH.step
cad/SUPPORT_HEX_M3_0XL35_FF.step
cad/SUPPORT_HEX_M3_0XL45_FF.step
cad/Second Floor.step
cad/Solenoid_holder.STL
cad/SolidWorks_source/IR_sensor_holder.SLDPRT
cad/SolidWorks_source/Shooter - Friction Wheel/.stl files/Cannon_2.STL
cad/SolidWorks_source/Shooter - Friction Wheel/Cannon_2.SLDPRT
cad/SolidWorks_source/Shooter - Friction Wheel/Friction_wheel.SLDPRT
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

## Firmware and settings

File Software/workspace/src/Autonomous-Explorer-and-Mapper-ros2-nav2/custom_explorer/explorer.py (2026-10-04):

import math
import time
import numpy as np

# ROS 2 & Middleware Abstraction (Permits both real ROS 2 and standalone simulation test execution)
try:
    import rclpy
    from rclpy.node import Node
    from nav_msgs.msg import OccupancyGrid, Odometry
    from geometry_msgs.msg import PoseStamped
    from nav2_msgs.action import NavigateToPose
    from rclpy.action import ActionClient
    from std_msgs.msg import String
    HAS_ROS = True
except (ImportError, ModuleNotFoundError):
    HAS_ROS = False
    class Node:
        def __init__(self, name):
            self._name = name
        def create_subscription(self, *args, **kwargs): return None
        def create_timer(self, *args, **kwargs): return None
        def get_logger(self):
            class L:
                def info(self, m): pass
                def warn(self, m): pass
                def error(self, m): pass
            return L()
        def declare_parameter(self, *args, **kwargs): pass
        def get_parameter(self, name):
            class P:
                class V:
                    def bool_value(self): return True
                    def double_value(self): return 30.0
                def get_parameter_value(self): return self.V()
            return P()
    class ActionClient:
        def __init__(self, *args, **kwargs): pass
        def wait_for_server(self, timeout_sec=1.0): return True
        def send_goal_async(self, goal):
            class F:
                def add_done_callback(self, cb): pass
            return F()
    class OccupancyGrid: pass
    class Odometry: pass
    class PoseStamped:
        def __init__(self):
            class H:
                stamp = None
                frame_id = 'map'
            self.header = H()
            class P:
                class Pos:
                    x = 0.0
                    y = 0.0
                    z = 0.0
                class Orient:
                    x = 0.0
                    y = 0.0
                    z = 0.0
                    w = 1.0
                position = Pos()
                orientation = Orient()
            self.pose = P()
    class NavigateToPose:
        class Goal:
            pose = None
    class String:
        def __init__(self): self.data = ""

try:
    import tf_transformations
except (ImportError, ModuleNotFoundError):
    class tf_transformations:
        @staticmethod
        def euler_from_quaternion(q):
            x, y, z, w = q
            siny_cosp = 2.0 * (w * z + x * y)
            cosy_cosp = 1.0 - 2.0 * (y * y + z * z)
            yaw = math.atan2(siny_cosp, cosy_cosp)
            return (0.0, 0.0, yaw)

        @staticmethod
        def quaternion_from_euler(roll, pitch, yaw):
            cy = math.cos(yaw * 0.5)
            sy = math.sin(yaw * 0.5)
            return (0.0, 0.0, sy, cy)

# Hardware abstraction for GPIO
try:
    import RPi.GPIO as GPIO
    HAS_GPIO = True
except (ImportError, RuntimeError):
    HAS_GPIO = False


class ExplorerNode(Node):
    def __init__(self):
        super().__init__('explorer')
        self.get_logger().info("Explorer Node Started")

        # Parameters
        self.declare_parameter('is_sim', False)
        self.declare_parameter('heat_threshold', 30.0)
        self.is_sim = self.get_parameter('is_sim').get_parameter_value().bool_value

        # Subscriptions
        self.map_sub = self.create_subscription(OccupancyGrid, '/map', self.map_callback, 10)
        self.thermal_sub = self.create_subscription(String, '/thermal_data', self.thermal_callback, 10)
        self.odom_sub = self.create_subscription(Odometry, '/odom', self.odom_callback, 10)

        # Action client for Nav2
        self.nav_to_pose_client = ActionClient(self, NavigateToPose, 'navigate_to_pose')

        # Navigation state tracking
        self.is_navigating = False
        self.current_goal_handle = None
        self.active_frontier = None

        # Robot position & pose in world coordinates (meters & radians)
        self.robot_position = (0.0, 0.0)
        self.current_yaw = 0.0

        # Visited frontiers and targets
        self.visited_frontiers = set()
        self.blacklisted_frontiers = set()
        self.visited_heat_sources = []
        self.heat_source = None
        self.followingHeat = None

        # Map state
        self.map_data = None

        # Setup GPIO if running on hardware
        if HAS_GPIO and not self.is_sim:
            try:
                GPIO.setmode(GPIO.BCM)
                GPIO.setup(18, GPIO.OUT)
                GPIO.setup(17, GPIO.OUT)
                GPIO.setup(27, GPIO.OUT)
                GPIO.output(17, GPIO.HIGH)
                GPIO.output(27, GPIO.LOW)
                self.get_logger().info("Hardware GPIO initialized successfully.")
            except Exception as e:
                self.get_logger().warn(f"Failed to initialize GPIO: {e}")
        else:
            self.get_logger().info("Running in SIMULATION mode: Hardware GPIO mocked.")

        # Timer for periodic exploration / state machine
        self.timer = self.create_timer(2.0, self.check_heat_source)

    def map_callback(self, msg):
        self.map_data = msg

    def odom_callback(self, msg):
        position = msg.pose.pose.position
        self.robot_position = (position.x, position.y)

        orientation_q = msg.pose.pose.orientation
        quat = (orientation_q.x, orientation_q.y, orientation_q.z, orientation_q.w)
        roll, pitch, self.current_yaw = tf_transformations.euler_from_quaternion(quat)

    def thermal_callback(self, msg):
        self.heat_source = msg.data.strip() if msg.data else None

    def startFiring(self):
        """Non-blocking simulated or hardware firing sequence."""
        self.get_logger().info("🔥 EXECUTING TARGET FIRING SEQUENCE 🔥")
        if HAS_GPIO and not self.is_sim:
            try:
                GPIO.output(18, GPIO.HIGH)
                time.sleep(0.5)
                GPIO.output(18, GPIO.LOW)
            except Exception as e:
                self.get_logger().error(f"GPIO firing error: {e}")
        else:
            self.get_logger().info("[SIMULATION] Cam launcher motor pulsed -> Projectile fired!")

    def check_heat_source(self):
        """Main decision loop: prioritizing thermal targets over frontier exploration."""
        if self.map_data is None:
            self.get_logger().info("Waiting for map data...")
            return

        # If we have an active heat signature, prioritize it!
        if self.heat_source and self.heat_source != "N":
            self.get_logger().info(f"Thermal target active: {self.heat_source}")
            command = self.heat_source[0]
            
            if command == "L":
                self.turn_relative(math.pi / 4)
            elif command == "R":
                self.turn_relative(-math.pi / 4)
            elif command == "F":
                pixel_str = self.heat_source[1:]
                pixels = int(pixel_str) if pixel_str.isdigit() else 10
                
                target_x, target_y = self.getCoordinates(pixels)
                already_visited = any(
                    math.hypot(target_x - hx, target_y - hy) < 0.3
                    for (hx, hy) in self.visited_heat_sources
                )
                if already_visited:
                    self.get_logger().info("Target already visited; resuming exploration.")
                    self.explore()
                else:
                    self.move_forward(pixels)
            elif command == "S":
                self.startFiring()
                self.visited_heat_sources.append(self.robot_position)
                self.heat_source = None
                self.explore()
            return

        # No heat detected: if not currently navigating, explore frontiers
        if not self.is_navigating:
            self.explore()

    def getForwardDistance(self, pixels):
        if pixels > 32:
            return 0.1
        elif pixels > 8:
            return 0.25
        else:
            return 0.50

    def getCoordinates(self, pixels):
        robot_x, robot_y = self.robot_position
        dist = self.getForwardDistance(pixels)
        target_x = robot_x + dist * math.cos(self.current_yaw)
        target_y = robot_y + dist * math.sin(self.current_yaw)
        return (target_x, target_y)

    def move_forward(self, pixels):
        target_x, target_y = self.getCoordinates(int(pixels))
        self.followingHeat = (target_x, target_y)
        self.navigate_to(target_x, target_y, self.current_yaw)

    def turn_relative(self, angle_rad):
        new_yaw = self.current_yaw + angle_rad
        new_yaw = (new_yaw + math.pi) % (2 * math.pi) - math.pi
        self.navigate_to(self.robot_position[0], self.robot_position[1], new_yaw)

    def navigate_to(self, x, y, yaw=None):
        if yaw is None:
            yaw = self.current_yaw

        if not self.nav_to_pose_client.wait_for_server(timeout_sec=1.0):
            self.get_logger().warn("Nav2 action server 'navigate_to_pose' not available.")
            return

        goal_msg = PoseStamped()
        goal_msg.header.frame_id = 'map'
        if HAS_ROS:
            goal_msg.header.stamp = self.get_clock().now().to_msg()
        goal_msg.pose.position.x = float(x)
        goal_msg.pose.position.y = float(y)

        q = tf_transformations.quaternion_from_euler(0, 0, yaw)
        goal_msg.pose.orientation.x = q[0]
        goal_msg.pose.orientation.y = q[1]
        goal_msg.pose.orientation.z = q[2]
        goal_msg.pose.orientation.w = q[3]

        nav_goal = NavigateToPose.Goal()
        nav_goal.pose = goal_msg

        self.get_logger().info(f"Navigating to: ({x:.2f}, {y:.2f}), yaw={yaw:.2f}")
        send_goal_future = self.nav_to_pose_client.send_goal_async(nav_goal)
        send_goal_future.add_done_callback(self.goal_response_callback)
        self.is_navigating = True

    def goal_response_callback(self, future):
        goal_handle = future.result()
        if not goal_handle.accepted:
            self.get_logger().warn("Goal rejected by Nav2!")
            self.is_navigating = False
            if self.active_frontier:
                self.blacklisted_frontiers.add(self.active_frontier)
                self.active_frontier = None
            self.explore()
            return

        self.get_logger().info("Goal accepted by Nav2")
        self.current_goal_handle = goal_handle
        result_future = goal_handle.get_result_async()
        result_future.add_done_callback(self.navigation_complete_callback)

    def navigation_complete_callback(self, future):
        self.is_navigating = False
        try:
            result = future.result().result
            if self.followingHeat:
                self.visited_heat_sources.append(self.followingHeat)
                self.followingHeat = None
            self.get_logger().info(f"Navigation completed with status: {result}")
        except Exception as e:
            self.get_logger().error(f"Navigation error: {e}")

        self.explore()

    def find_frontiers(self, map_array):
        """Fast vectorized frontier detection in 2D OccupancyGrid."""
        is_free = (map_array == 0)
        is_unknown = (map_array == -1)

        has_unknown_neighbor = (
            is_unknown[:-2, :-2] | is_unknown[:-2, 1:-1] | is_unknown[:-2, 2:] |
            is_unknown[1:-1, :-2] |                        is_unknown[1:-1, 2:] |
            is_unknown[2:, :-2]  | is_unknown[2:, 1:-1]  | is_unknown[2:, 2:]
        )

        frontier_mask = is_free[1:-1, 1:-1] & has_unknown_neighbor
        rows, cols = np.where(frontier_mask)
        rows = rows + 1
        cols = cols + 1

        frontiers = list(zip(rows, cols))
        return frontiers

    def choose_frontier(self, frontiers):
        """Choose closest valid frontier using real-world Euclidean distance in METERS."""
        if not frontiers:
            return None

        robot_x, robot_y = self.robot_position
        res = self.map_data.info.resolution
        origin_x = self.map_data.info.origin.position.x
        origin_y = self.map_data.info.origin.position.y

        min_distance = float('inf')
        chosen_frontier = None

        for r, c in frontiers:
            if (r, c) in self.visited_frontiers or (r, c) in self.blacklisted_frontiers:
                continue

            fx = c * res + origin_x
            fy = r * res + origin_y
            dist = math.hypot(robot_x - fx, robot_y - fy)

            if 0.3 < dist < min_distance:
                min_distance = dist
                chosen_frontier = (r, c)

        if chosen_frontier:
            self.visited_frontiers.add(chosen_frontier)
            self.active_frontier = chosen_frontier
            self.get_logger().info(f"Selected nearest frontier at cell {chosen_frontier}, dist={min_distance:.2f}m")
        return chosen_frontier

    def explore(self):
        if self.map_data is None:
            return

        map_array = np.array(self.map_data.data).reshape(
            (self.map_data.info.height, self.map_data.info.width)
        )

        frontiers = self.find_frontiers(map_array)
        if not frontiers:
            self.get_logger().info("No frontiers detected. Exploration fully complete!")
            return

        chosen = self.choose_frontier(frontiers)
        if not chosen:
            self.get_logger().info("All current frontiers visited or blacklisted.")
            return

        goal_x = chosen[1] * self.map_data.info.resolution + self.map_data.info.origin.position.x
        goal_y = chosen[0] * self.map_data.info.resolution + self.map_data.info.origin.position.y

        yaw = math.atan2(goal_y - self.robot_position[1], goal_x - self.robot_position[0])
        self.navigate_to(goal_x, goal_y, yaw)


def main(args=None):
    if HAS_ROS:
        rclpy.init(args=args)
        explorer_node = ExplorerNode()
        try:
            rclpy.spin(explorer_node)
        except KeyboardInterrupt:
            explorer_node.get_logger().info("Exploration stopped by user.")
        finally:
            if HAS_GPIO:
                try:
                    GPIO.cleanup()
                except Exception:
                    pass
            explorer_node.destroy_node()
            rclpy.shutdown()
    else:
        print("ROS 2 environment not detected. Use test harness for standalone execution.")


if __name__ == '__main__':
    main()

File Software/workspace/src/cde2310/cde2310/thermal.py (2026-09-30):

import time
import rclpy
from rclpy.node import Node
from std_msgs.msg import String

# Hardware I2C packages
try:
    import board
    import busio
    import adafruit_amg88xx
    HAS_AMG = True
except (ImportError, NotImplementedError, AttributeError):
    HAS_AMG = False


class ThermalPublisher(Node):
    def __init__(self):
        super().__init__('thermal_publisher')
        
        self.declare_parameter('use_sim', False)
        self.declare_parameter('threshold', 30.0)
        self.use_sim = self.get_parameter('use_sim').get_parameter_value().bool_value
        self.threshold = self.get_parameter('threshold').get_parameter_value().double_value

        self.sensor = None
        if HAS_AMG and not self.use_sim:
            try:
                i2c_bus = busio.I2C(board.SCL, board.SDA)
                self.sensor = adafruit_amg88xx.AMG88XX(i2c_bus)
                self.get_logger().info("Hardware AMG8833 thermal sensor connected via I2C.")
            except Exception as e:
                self.get_logger().warn(f"Failed to connect AMG8833 sensor: {e}. Falling back to simulation.")
                self.sensor = None
        else:
            self.get_logger().info("Thermal Publisher started in SIMULATION mode.")

        # ROS Publisher
        self.publisher_ = self.create_publisher(String, 'thermal_data', 10)
        
        # In simulation, subscribe to a simulated raw grid or coordinate if available
        self.sim_thermal_sub = self.create_subscription(
            String, 'sim_thermal_command', self.sim_command_callback, 10
        )
        self.sim_command = "N"

        # Timer to publish data every 1 second
        self.timer = self.create_timer(1.0, self.publish_thermal_data)
        self.get_logger().info("Thermal Publisher Node Initialized")

    def sim_command_callback(self, msg):
        self.sim_command = msg.data.strip()

    def publish_thermal_data(self):
        if self.sensor is not None:
            direction = self.analyze_sensor_data()
        else:
            direction = self.sim_command

        msg = String()
        msg.data = direction
        self.publisher_.publish(msg)
        if direction != "N":
            self.get_logger().info(f"Published Thermal Command: {msg.data}")

    def analyze_sensor_data(self):
        try:
            sensor_data = self.sensor.pixels
        except Exception as e:
            self.get_logger().error(f"Error reading I2C sensor: {e}")
            return "N"

        threshold = self.threshold
        total_pixels = len(sensor_data) * len(sensor_data[0])
        above_threshold = sum(1 for row in sensor_data for pixel in row if pixel > threshold)

        # All dots below threshold
        if above_threshold < 0.05 * total_pixels:
            return "N"

        # If >50% pixels above threshold -> Close enough to shoot!
        if above_threshold >= 0.5 * total_pixels:
            return "S"

        left_count = sum(1 for row in sensor_data for i in range(4) if row[i] > threshold)
        right_count = sum(1 for row in sensor_data for i in range(4, 8) if row[i] > threshold)
        center_count = sum(1 for row in sensor_data for i in range(2, 6) if row[i] > threshold)

        if center_count > left_count and center_count > right_count:
            return f"F{center_count}"
        elif left_count > right_count:
            return "L"
        else:
            return "R"


def main(args=None):
    rclpy.init(args=args)
    node = ThermalPublisher()
    try:
        rclpy.spin(node)
    except KeyboardInterrupt:
        node.get_logger().info("Shutting down Thermal Publisher")
    finally:
        node.destroy_node()
        rclpy.shutdown()


if __name__ == '__main__':
    main()

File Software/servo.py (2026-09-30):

import RPi.GPIO as GPIO
import time

# Define GPIO pin for servo
SERVO_PIN = 13  

# Setup GPIO
GPIO.setmode(GPIO.BCM)
GPIO.setup(SERVO_PIN, GPIO.OUT)

# Start PWM at 50Hz
pwm = GPIO.PWM(SERVO_PIN, 50)  
pwm.start(0)

def set_angle(angle):
    duty_cycle = angle / 18 + 2  # Convert angle to duty cycle
    GPIO.output(SERVO_PIN, True)
    pwm.ChangeDutyCycle(duty_cycle)
    time.sleep(0.5)
    GPIO.output(SERVO_PIN, False)
    pwm.ChangeDutyCycle(0)

try:
    # Move to 0° position
    set_angle(0)
    print("Servo moved to 0°")
    time.sleep(2)  # Wait 2 seconds

    # Move to 45° position
    set_angle(45)
    print("Servo moved to 45°")

    set_angle(105)
    print("moved to 105deg")

    set_angle(180)
    print("moved to 180deg")

except KeyboardInterrupt:
    print("\nProgram interrupted.")

finally:
    pwm.stop()
    GPIO.cleanup()
    print("GPIO cleaned up.")
